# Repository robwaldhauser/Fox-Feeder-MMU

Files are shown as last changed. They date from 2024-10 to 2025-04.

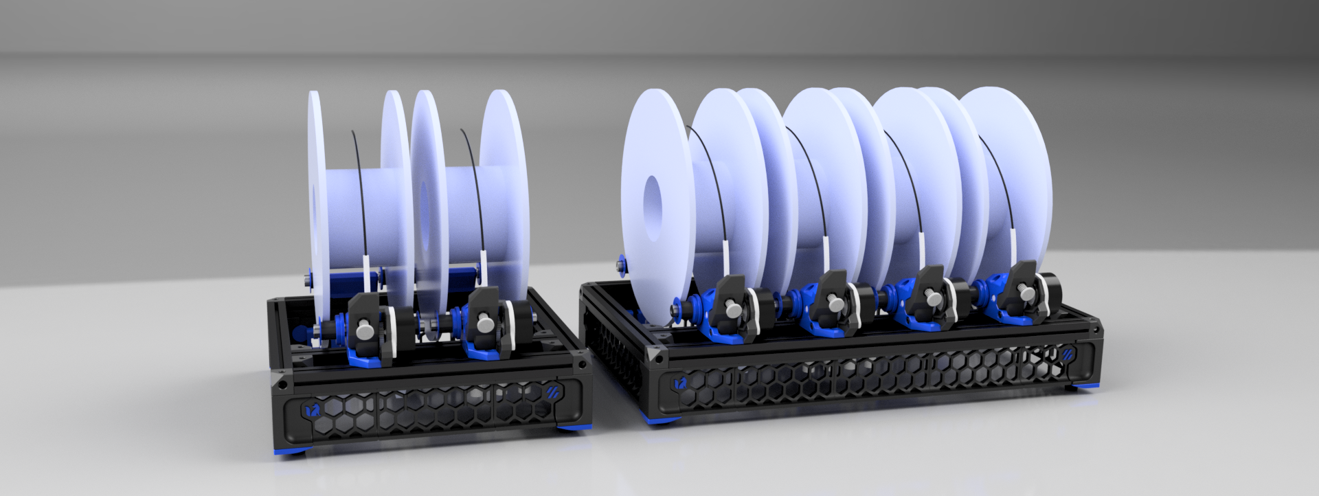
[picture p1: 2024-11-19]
Fox Feeder v138.png

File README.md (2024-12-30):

# Fox Feeder MMU 🦊

The FoxFeeder MMU is a low-cost, easy-to-build multi-material unit (MMU) designed to bring advanced multi-material printing capabilities to any 3D printer running Klipper. Inspired by the functionality of the BambuLab AMS, the FoxFeeder MMU is a lightweight low-cost solution that pairs seamlessly with the FriendlyFox macro package and the innovative Slacker sensor for precise filament tracking.
Fox Feeder v138
If you like this project, consider [tipping](https://www.Ko-fi.com/robxberty)!

## Features ✨

- Affordable: Designed with cost-effective components, making multi-material printing accessible.
- Customizable Lanes: Choose between 2-lane or 4-lane configurations to suit your needs (additional lanes may be supported in the future)
- Slacker Sensor Integration: Utilizes the Slacker Sensor for real-time monitoring of filament slack and tension through the Bowden tube, ensuring consistent filament flow.
- Seamless Integration: Built to work flawlessly with the FriendlyFox macro package. One .cfg to add and that's it, no plugins needed!
- Ease of Assembly: A straightforward assembly process suitable for hobbyists and newcomers alike.

## Table of Contents 📖

- Introduction
- [Features](https://github.com/robwaldhauser/Fox-Feeder-MMU#features-)
- [Requirements](https://github.com/robwaldhauser/Fox-Feeder-MMU#requirements-)
- [Assembly Instructions](https://github.com/robwaldhauser/Fox-Feeder-MMU#assembly-instructions-)
- [Configuration](https://github.com/robwaldhauser/Fox-Feeder-MMU#configuration-)
- [Usage](https://github.com/robwaldhauser/Fox-Feeder-MMU#usage-)
- [Roadmap](https://github.com/robwaldhauser/Fox-Feeder-MMU#roadmap-)
- [Contributing](https://github.com/robwaldhauser/Fox-Feeder-MMU#contributing-)
- [License](https://github.com/robwaldhauser/Fox-Feeder-MMU#license-)

## Requirements 🛠️

- A 3D printer with Bowden setup or compatible extruder system.
- A set of printed components for the FoxFeeder (STL files available in the STLs directory).
- Hardware kit (refer to the Bill of Materials).
- Slacker Sensor for filament slack detection (available from the Slacker repository).
- FriendlyFox Macro Package (available from the FriendlyFox repository).

## Printing Instructions

- Designed to follow Voron printing standards. General rule is 0.4mm line widths, 4 walls, 5 tops and bottoms, and 40% infill. Adjust at your own risk.
- All items with an [a] prefix are intended to be your accent color
- All items with a [s] prefix are best to be printed in a [s]oft but not too [s]quishy filament to keep things [s]ilent. This can be a medium to hard tpu.
- All items that need supports, have them built in.
- The Roller Clutch Inner parts are designed to have an overhang for the pinwheels. You will want to gently free them up after printing but before assembly.

## Assembly Instructions 🔧

- Assemble your frame using Corner Cubes. The center cross bar will need to have a 31mm gap between it and the front extrusion. The tapered corners of the Corner Cubes will face up and outward.
- Feet and Skirts assemble exactly like a Voron 0.
- **more instructions to come, this is currently being updated**

## Configuration ⚙️

To integrate the FoxFeeder MMU with your printer and firmware:

- Install the FriendlyFox Macro Package, simply copy the FriendlyFox.cfg file into your Klipper instance. Be sure to include it in your printer.cfg
- Configure your slicer to define the number of active lanes.
- Update your printer's Klipper configuration with the provided example configurations in configs/.

## Usage 🚀

Once set up, the FoxFeeder MMU will:

- Detect and manage filament slack using the Slacker Sensor.
- Switch lanes seamlessly during multi-material prints.
- Operate efficiently and reliably under the control of the FriendlyFox macros.

Refer to the Usage Guide for detailed instructions.

## Roadmap 🛣️

- Add support for more lanes (e.g., 6-lane or 8-lane configurations).
- Improve documentation and troubleshooting guides.
- Create community challenges and showcases.

## Contributing 🤝

Contributions are welcome! Feel free to submit issues, feature requests, and pull requests. Check the Contributing Guide for more details.
Please also consider [tipping](https://www.Ko-fi.com/robxberty) to help with further development!

## License 📄

This project is licensed under the MIT License.

## Join the FoxFeeder revolution and unleash the power of multi-material printing without breaking the bank! 🦊

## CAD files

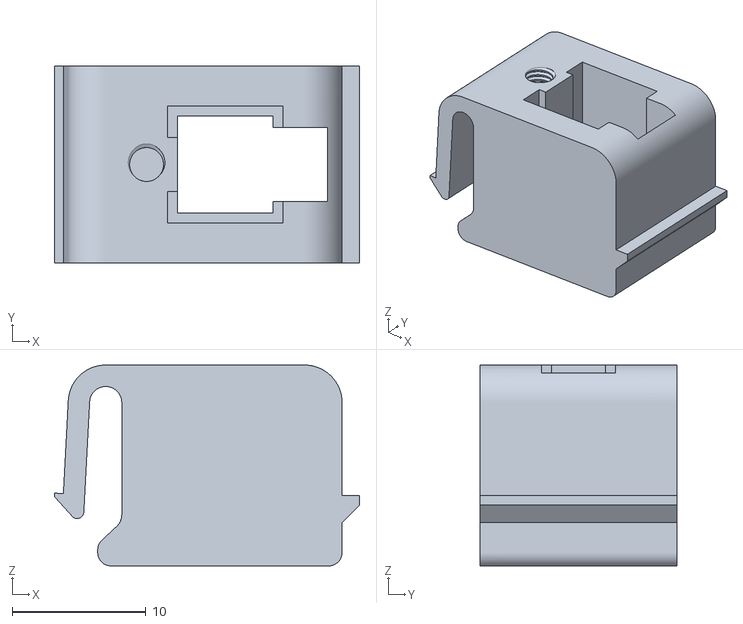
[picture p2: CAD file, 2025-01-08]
STLs/Electronics/Micro-Fit 2x2 Keystone.stl
22.8 x 14.7 x 15.0

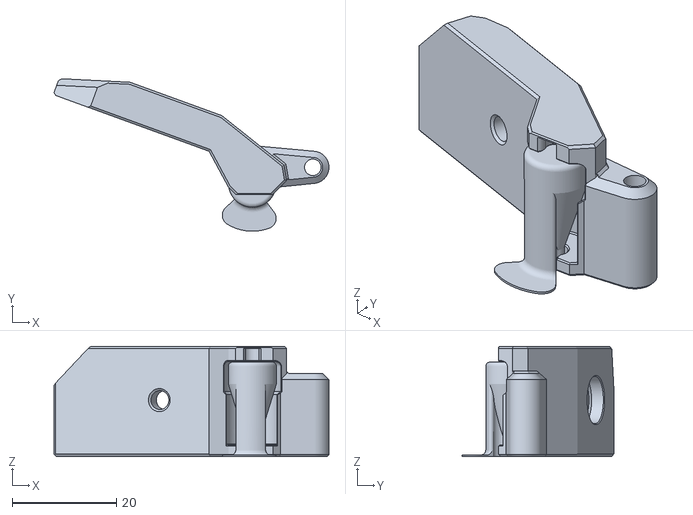
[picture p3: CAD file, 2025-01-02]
STLs/Extruder/Tensioner Arm xN.stl
52.7 x 29.2 x 21.1

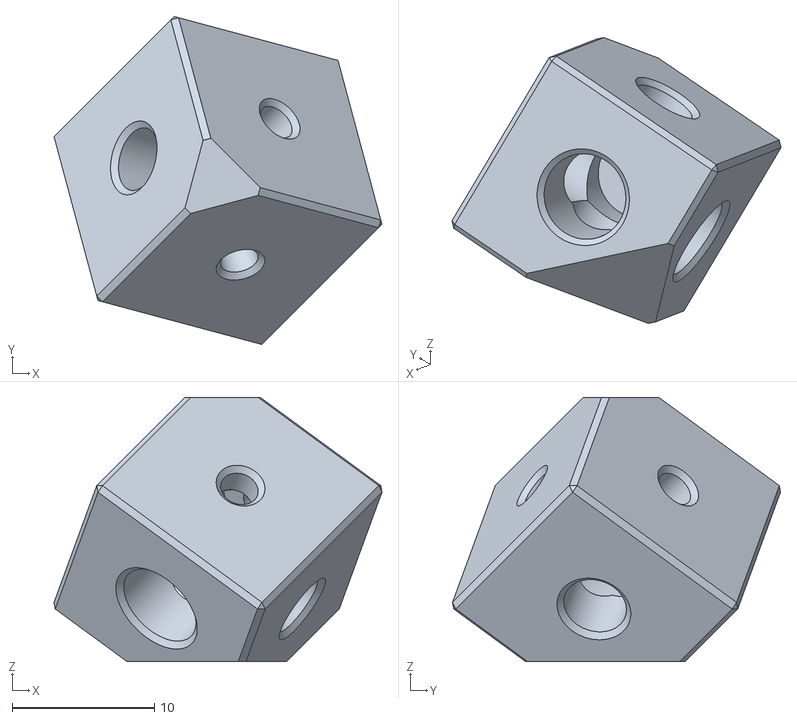
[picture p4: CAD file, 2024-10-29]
STLs/Frame/Corner Cube x8.stl
23.0 x 23.0 x 18.6

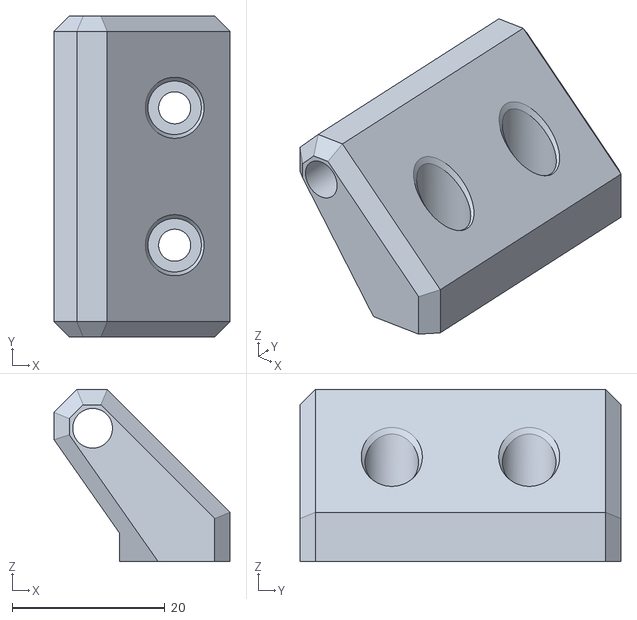
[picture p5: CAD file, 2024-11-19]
STLs/Idler/[a] Idler Body xN.stl
23.1 x 42.0 x 22.5

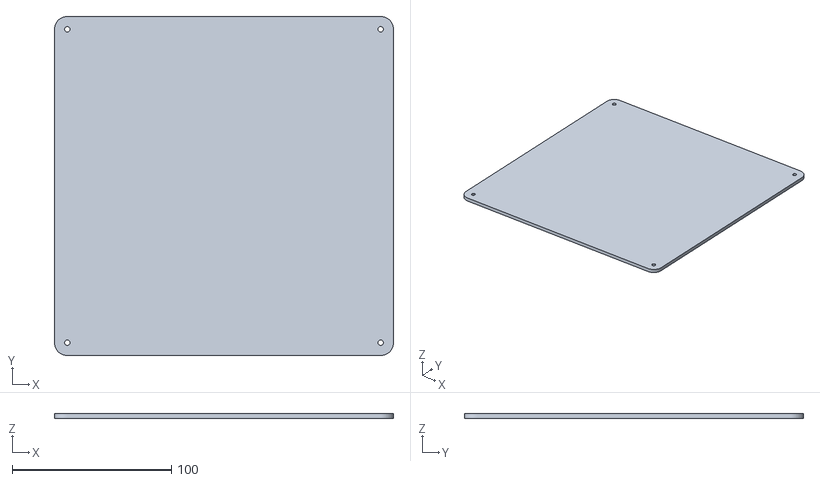
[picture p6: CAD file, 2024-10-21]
STLs/Panels/Bottom Panel.stl
213.0 x 213.0 x 3.00

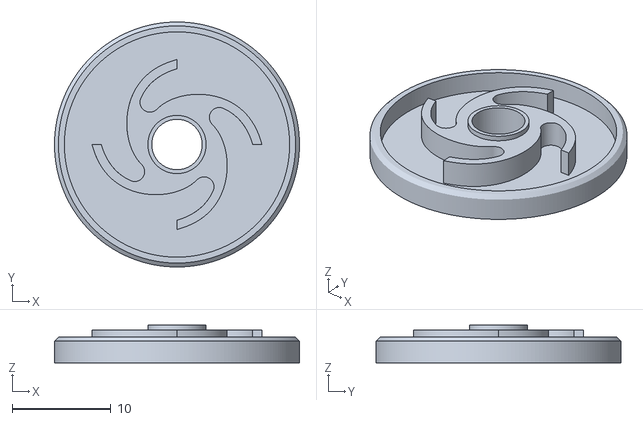
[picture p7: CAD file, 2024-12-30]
STLs/Rollers (TPU)/[s] Left Roller Clutch Inner xN.stl
24.8 x 24.8 x 3.80

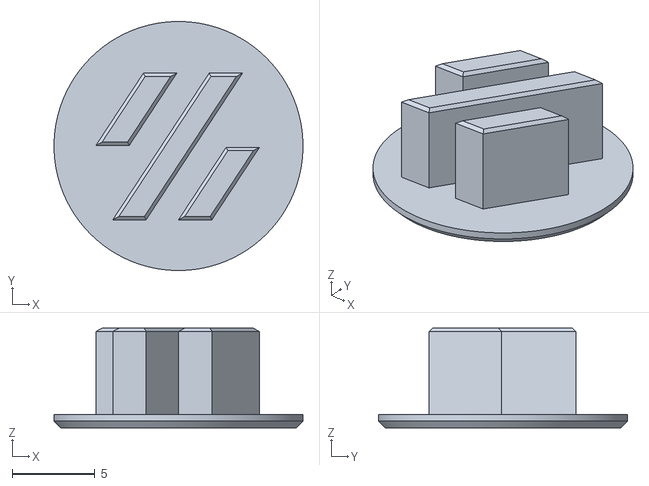
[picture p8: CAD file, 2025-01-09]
STLs/Skirts/(a) V Logo Insert.stl
15.0 x 15.0 x 6.00

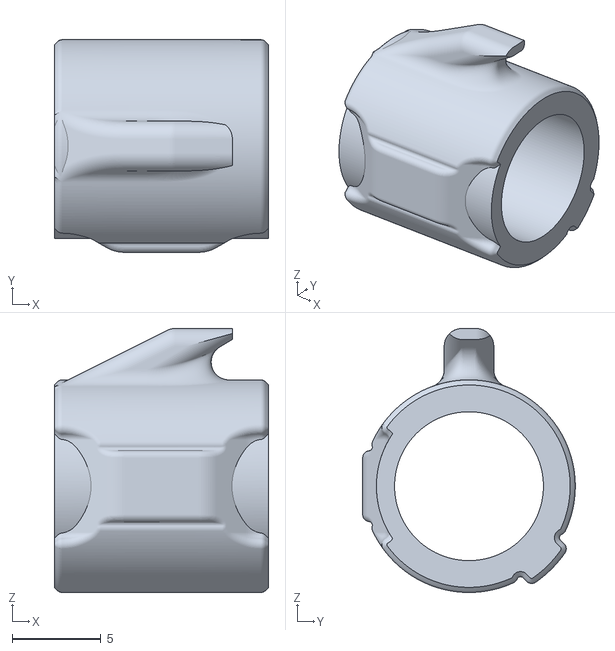
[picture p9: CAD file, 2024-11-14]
STLs/Slacker/[a] Slider W Bands.stl
12.1 x 12.0 x 14.9

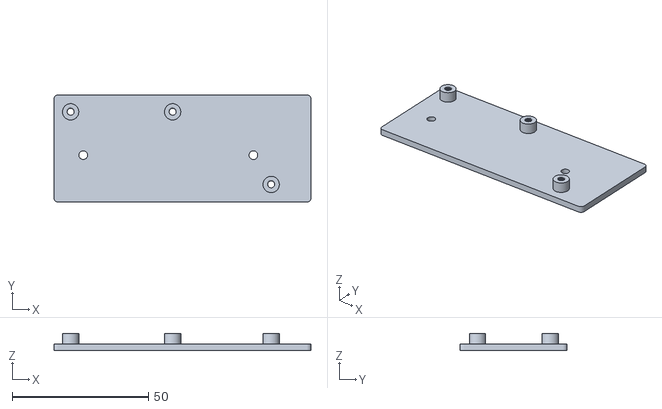
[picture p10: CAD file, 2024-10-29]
STLs/Electronics/ERB Bracket.stl
94.4 x 39.4 x 6.40

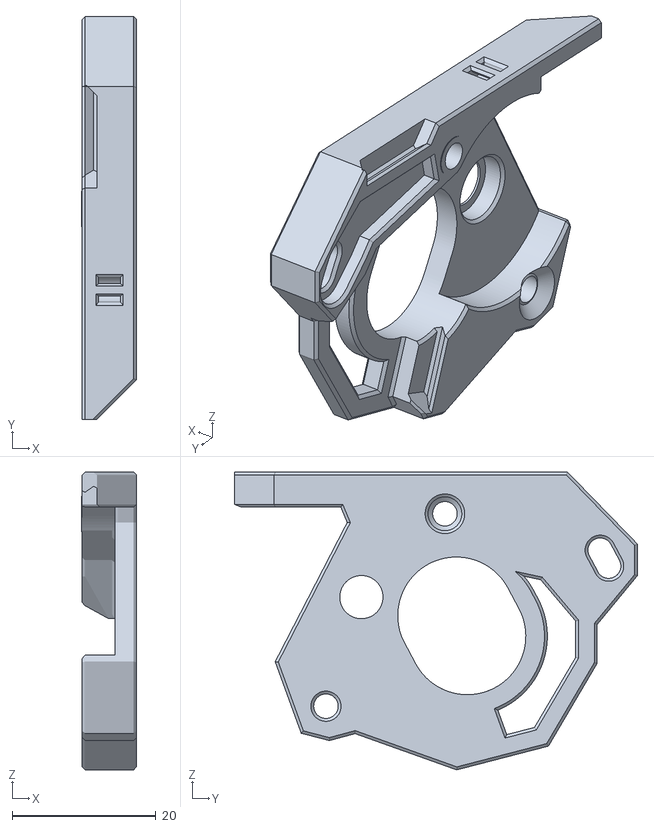
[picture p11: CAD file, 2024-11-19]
STLs/Extruder/Motor Plate xN.stl
7.65 x 56.0 x 41.4

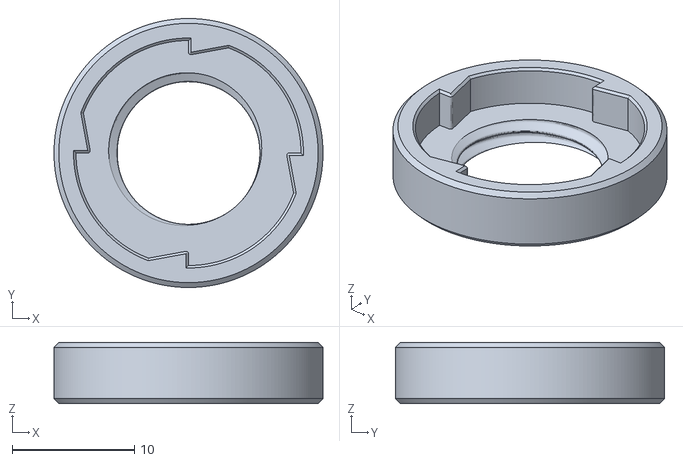
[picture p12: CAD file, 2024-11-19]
STLs/Rollers (TPU)/[s] Right Roller Clutch Outer xN.stl
22.0 x 22.0 x 5.00

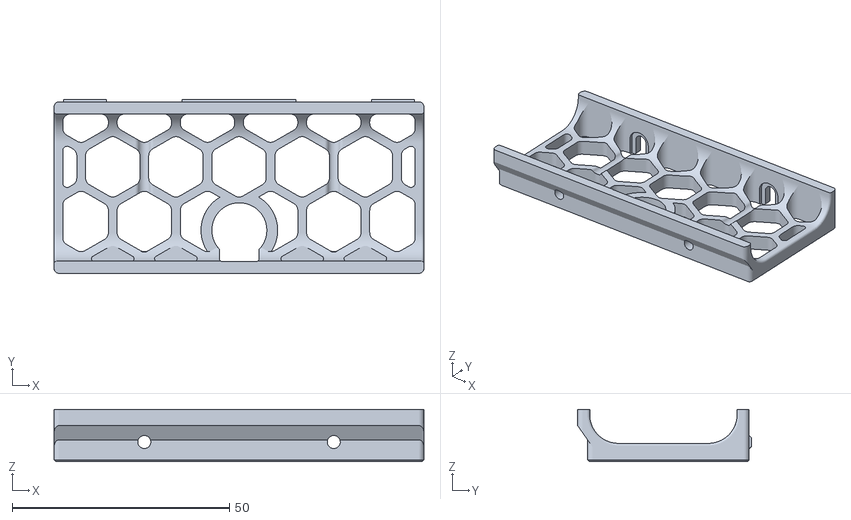
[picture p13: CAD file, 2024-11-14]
STLs/Skirts/Rear Center Skirt Slacker.stl
85.2 x 40.0 x 12.0

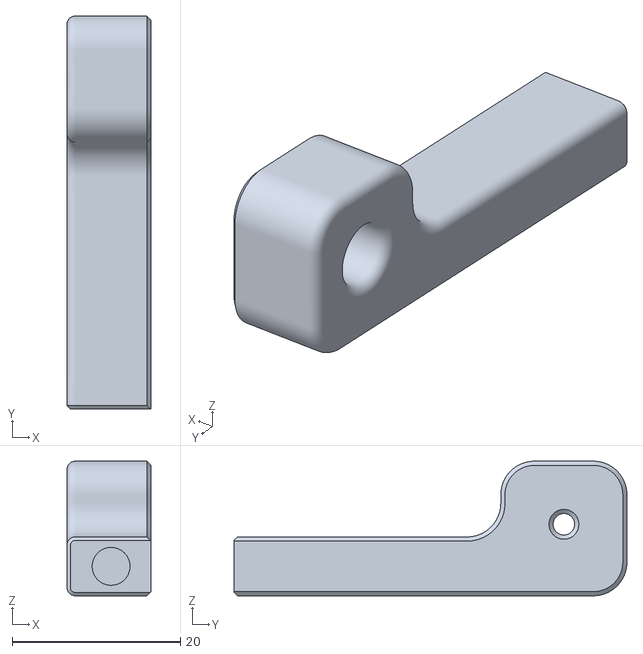
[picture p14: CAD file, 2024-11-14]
STLs/Slacker/Slacker Brace.stl
10.0 x 46.7 x 16.0

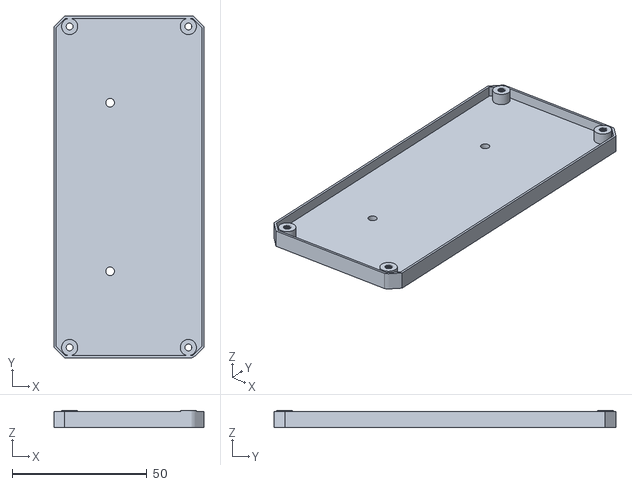
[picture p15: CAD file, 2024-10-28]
STLs/Electronics/MMB Bracket.stl
55.6 x 126.6 x 6.40

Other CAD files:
STLs/Extruder/[a] Extruder Body xN.stl
STLs/Skirts/Foot B x2.stl
STLs/Slacker/Sensor Housing w Bands.stl
STLs/Rollers (TPU)/[s] Right Roller Clutch Inner xN.stl
STLs/Rollers (TPU)/OLD [s] Left Roller Clutch Inner xN.stl
STLs/Rollers (TPU)/[s] Idler Inner x2N.stl
STLs/Rollers (TPU)/[s] Left Roller Clutch Outer xN.stl
STLs/Rollers (TPU)/[s] Roller x4N.stl
STLs/Skirts/(a) Foot Accent A x2.stl
STLs/Skirts/(a) Foot Accent B x2.stl
STLs/Skirts/(a) Fox Logo Insert x2.stl
STLs/Skirts/(s) Rubber Foot x4.stl
STLs/Skirts/Foot A x2.stl
STLs/Skirts/Front Center Skirt.stl
STLs/Skirts/Rear Left Skirt.stl
STLs/Skirts/Side Skirt A x2.stl
STLs/Skirts/Side Skirt B x2.stl
STLs/Skirts/Skirt A x2.stl
STLs/Skirts/Skirt B.stl
STLs/Slacker/Slider.stl

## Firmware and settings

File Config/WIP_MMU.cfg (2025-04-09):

[force_move]
enable_force_move: True
#   Set to true to enable FORCE_MOVE and SET_KINEMATIC_POSITION
#   extended G-Code commands. The default is false.

#Variable Store
[gcode_macro _FILAMENT_VARS]
variable_activelane: None
variable_lane_count: 2 # Number of lanes to look for
variable_infinitespool: 1
variable_bowden_length: 980 # Run the MEASURE_BOWDEN macro to get an estimate for this value
variable_filament_feed_length: 105 # The amount of travel needed to clear extruder on filament removal.
variable_stepper_accel: 150
variable_stepper_speed: 45
variable_bowden_calculate: 0
variable_pause_flag: False
variable_slacker_enabled: False
gcode: # Gcode section left intentionally blank. Do not disturb.

    {action_respond_info(" Running the VARIABLE_STORE macro does nothing")}

[mcu pcu]
canbus_uuid: 2c180b4d19b3

# Aliases for easier configuration.

[board_pins pcu_alias]
mcu: pcu
aliases:
aliases_both_sides:
  taut=PA3,
  slack=PA4,
aliases_lane0:
  sensor_0=PB9,
  lane0_step=PB15,
  lane0_dir=PB14,
  lane0_enable=PA8,
  lane0_uart=PA10,
aliases_lane1:
  sensor_1=PB8,
  lane1_step=PD2,
  lane1_dir=PB13,
  lane1_enable=PD1,
  lane1_uart=PC7,


#
# Below are the stepper configs, you will need one for each lane
#

[extruder_stepper stepper_0]
extruder: 
step_pin: pcu:lane0_step
dir_pin: pcu:lane0_dir
enable_pin: !pcu:lane0_enable
microsteps: 16
rotation_distance: 22 
gear_ratio: 50:10 # CW2 gear ratio
microsteps: 16
full_steps_per_rotation: 200

[tmc2209 extruder_stepper stepper_0]
uart_pin: pcu:lane0_uart
run_current: 0.8
hold_current: .1
stealthchop_threshold: 0
interpolate: True

[extruder_stepper stepper_1]
extruder: 
step_pin: pcu:lane1_step
dir_pin: pcu:lane1_dir
enable_pin: !pcu:lane1_enable
microsteps: 16
rotation_distance: 22 #16.27062274656 
gear_ratio: 50:10 # CW2 gear ratio
microsteps: 16
full_steps_per_rotation: 200

[tmc2209 extruder_stepper stepper_1]
uart_pin: pcu:lane1_uart
run_current: 0.8
hold_current: .1
stealthchop_threshold: 0
interpolate: True

#
# Sensors below, you will need 1 Belay sensor and then 1 sensor for each lane
#

#[belay belay0]
#extruder_type: extruder_stepper
#extruder_stepper_name: stepper_1
#sensor_pin: ^!pcu:belay
#multiplier_high: 1.3
#multiplier_low: .7
#debug_level: 1

[filament_switch_sensor taut]
switch_pin: ^!pcu:taut
pause_on_runout: False
runout_gcode:
  {% set lane = printer["gcode_macro _FILAMENT_VARS"].activelane %}
  RESPOND MSG="Lane {lane}: TAUT"
  FORCE_MOVE STEPPER="extruder_stepper stepper_{lane}" DISTANCE=6 VELOCITY=50 ACCEL=600

[filament_switch_sensor slack]
switch_pin: ^!pcu:slack
pause_on_runout: False
runout_gcode:
  {% set lane = printer["gcode_macro _FILAMENT_VARS"].activelane %}
  RESPOND MSG="Lane {lane}: SLACK"
  FORCE_MOVE STEPPER="extruder_stepper stepper_{lane}" DISTANCE=-6 VELOCITY=50 ACCEL=600

[filament_switch_sensor sensor_0]
switch_pin: ^pcu:sensor_0
pause_on_runout: False

[filament_switch_sensor sensor_1]
switch_pin: ^pcu:sensor_1
pause_on_runout: False

#
# Macros:
#

[gcode_macro SYNC_EXTRUDER]
gcode:
  {% set lane = params.LANE %}
  {% if not printer['extruder_stepper stepper_' + lane|string].motion_queue == 'extruder' %}
    SYNC_EXTRUDER_MOTION EXTRUDER=stepper_{lane} MOTION_QUEUE=extruder
  {% endif %}

[gcode_macro ISOLATE_EXTRUDER]
gcode:
  {% set lane = params.LANE %}
  {% if printer['extruder_stepper stepper_' + lane|string].motion_queue == 'extruder' %}
    SYNC_EXTRUDER_MOTION EXTRUDER=stepper_{lane} MOTION_QUEUE=
  {% endif %}

[gcode_macro CHECK_STATUS]
gcode:
  {% set lane = 0 %}
  {% set stepper_accel = printer["gcode_macro _FILAMENT_VARS"].stepper_accel %}
  {% for lane in range(printer["gcode_macro _FILAMENT_VARS"].lane_count) %}
    {% if printer['filament_switch_sensor sensor_' + lane|string].filament_detected and not printer["filament_switch_sensor taut"].filament_detected %}
      ISOLATE_EXTRUDER LANE={lane}
      FORCE_MOVE STEPPER="extruder_stepper stepper_{lane}" DISTANCE=6 VELOCITY=50 ACCEL={stepper_accel}
      M400 # Wait for buffer to clear
      {% set step = 0 %}
      {% for step in range(10) %}
        M400
        _PUSHING_CHECK LANE={lane} STEP={step}
        M400
      {% endfor %}
    {% elif printer['filament_switch_sensor sensor_' + lane|string].filament_detected %}
      ISOLATE_EXTRUDER LANE={lane}
      FORCE_MOVE STEPPER="extruder_stepper stepper_{lane}" DISTANCE=-6 VELOCITY=50 ACCEL={stepper_accel}
      M400 # Wait for buffer to clear
      {% set step = 0 %}
      {% for step in range(350) %}
        M400
        _PULLING_CHECK LANE={lane} STEP={step}
        M400
      {% endfor %}
    {% elif not printer['filament_switch_sensor sensor_' + lane|string].filament_detected %}
      ISOLATE_EXTRUDER LANE={lane}
      FORCE_MOVE STEPPER="extruder_stepper stepper_{lane}" DISTANCE=20 VELOCITY=50 ACCEL={stepper_accel}
      M400 # Wait for buffer to clear
      _CHECKING_LANE LANE={lane}
    #{% elif printer['filament_switch_sensor sensor_' + lane|string].filament_detected and not printer["filament_switch_sensor slack"].filament_detected %}
    #  ISOLATE_EXTRUDER LANE={lane}
    #  FORCE_MOVE STEPPER="extruder_stepper stepper_{lane}" DISTANCE=-10 VELOCITY=50 ACCEL={stepper_accel}
    #  M400 # Wait for buffer to clear
    #  _CHECKING_BELAY LANE={lane}
    {% else %}
      RESPOND MSG="Lane {lane}: No Filament is loaded"
    {% endif %}
  {% endfor %}

[gcode_macro _PUSHING_CHECK]
gcode:
  {% set lane = params.LANE %}
  {% set step = params.STEP|int %}
  {% set stepper_accel = printer["gcode_macro _FILAMENT_VARS"].stepper_accel %}
  {% if printer["filament_switch_sensor slack"].filament_detected and printer['filament_switch_sensor sensor_' + lane|string].filament_detected %}
    ISOLATE_EXTRUDER LANE={lane}
    M400
    FORCE_MOVE STEPPER="extruder_stepper stepper_{lane}" DISTANCE=6 VELOCITY=50 ACCEL={stepper_accel} 
    M400
  {% endif %}
  {% if step == 9 and not printer["filament_switch_sensor slack"].filament_detected and printer['filament_switch_sensor sensor_' + lane|string].filament_detected %}
    RESPOND MSG="Lane {lane} - Filament is at toolhead"
    SET_LANE LANE={lane}
  {% elif step == 9 %}
    REMOVE_FILAMENT LANE={lane}  SKIPCHECK=True
    RESPOND MSG="Lane {lane} - Filament is ready"
  {% endif %}

[gcode_macro _PULLING_CHECK]
gcode:
  {% set lane = params.LANE %}
  {% set step = params.STEP|int %}
  {% set stepper_accel = printer["gcode_macro _FILAMENT_VARS"].stepper_accel %}
  {% if printer["filament_switch_sensor taut"].filament_detected and printer['filament_switch_sensor sensor_' + lane|string].filament_detected %}
    ISOLATE_EXTRUDER LANE={lane}
    M400
    FORCE_MOVE STEPPER="extruder_stepper stepper_{lane}" DISTANCE=-6 VELOCITY=50 ACCEL={stepper_accel} 
    M400
  {% endif %}
  {% if step == 349 and not printer["filament_switch_sensor taut"].filament_detected and printer['filament_switch_sensor sensor_' + lane|string].filament_detected %}
    RESPOND MSG="Lane {lane} - Filament is at toolhead"
    SET_LANE LANE={lane}
  {% elif step == 349 %}
    RESPOND MSG="Lane {lane} - Filament is ready"
  {% endif %}

[gcode_macro _CHECKING_LANE]
gcode:
  {% set lane = params.LANE %}
  {% if not printer['filament_switch_sensor sensor_' + lane|string].filament_detected %}
    RESPOND MSG="Lane {lane}: No Filament is loaded"
  {% else %}
    REMOVE_FILAMENT LANE={lane}  SKIPCHECK=True
    RESPOND MSG="Lane {lane}: Filament is ready"
  {% endif %}

[gcode_macro SET_LANE]
gcode:
  {% set specified = params.SPECIFIED|default(None) %}
  {% if not specified == None %}
    RESPOND MSG="Activating Lane {specified}"
    SET_GCODE_VARIABLE MACRO=_FILAMENT_VARS VARIABLE=activelane VALUE={specified}
  {% elif printer['filament_switch_sensor sensor_0'].filament_detected and printer['filament_switch_sensor sensor_1'].filament_detected %}
    RESPOND TYPE=error msg="!! UNABLE TO DETECT SPOOL, BOTH SENSORS TRIGGERED !!"
  {% elif printer['filament_switch_sensor sensor_0'].filament_detected and not printer['filament_switch_sensor sensor_1'].filament_detected %}
    RESPOND MSG="Activating Lane 0"
    SET_GCODE_VARIABLE MACRO=_FILAMENT_VARS VARIABLE=activelane VALUE=0
  {% elif printer['filament_switch_sensor sensor_1'].filament_detected and not printer['filament_switch_sensor sensor_0'].filament_detected %}
    RESPOND MSG="Activating Lane 1"
    SET_GCODE_VARIABLE MACRO=_FILAMENT_VARS VARIABLE=activelane VALUE=1
  {% else %}
    RESPOND TYPE=error msg="!! UNKNOWN SPOOL CONFIGURATION !!"
  {% endif %}

[delayed_gcode INITIAL_SET_LANE]
initial_duration: 5
gcode:
  SET_FILAMENT_SENSOR SENSOR=taut ENABLE=0
  SET_FILAMENT_SENSOR SENSOR=slack ENABLE=0
  CHECK_STATUS
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

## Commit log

2024-10-21 Updates to STLs
    [(a) Extruder Body x(N).stl, (a) Foot Accent x4.stl, (a) Idler Bracket x(N).stl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]
2024-10-21 Update STLs
    [(a) Foot Accent A x2.stl, (a) Foot Accent B x2.stl, (a) Foot Accent x4.stl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]
2024-10-21 STL's Updates
    [(a) Logo Insert x4.stl, Bottom Panel.stl, Y Splitter Body.stl]
2024-10-28 Updates to STLs Folder
    [(a) Belay Slider.stl, (a) Extruder Body x(N).stl, (a) Fox Logo Insert x2.stl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]
2024-10-29 oriented stls
    fixed stl orientations
    [(a) Belay Slider.stl, (a) Extruder Body x(N).stl, (a) Fox Logo Insert x2.stl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]
2024-10-29 Updated CAD
2024-10-29 Update Belay Brace.stl
    accidentally saved cover as brace. fixed
    [Belay Brace.stl]
2024-10-29 Update Extruder Tension Arm x(N).stl
    [Extruder Tension Arm x(N).stl]
2024-10-29 orientation adjsted for printing
    fixed orientation
    [Corner Cube x8.stl, Extruder Tension Arm x(N).stl]
2024-10-29 Updated STLs
    [(a) Extruder Body x(N).stl, (a) Roller Caps x(4N).stl, Cap.stl]
2024-11-03 Updated CAD and STLS
    [(a) Extruder Body x(N).stl, (a) Idler Bracket x(N).stl, (s) Extruder Roller Sleeve Left x(N).stl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]
2024-11-05 STL Updates
    [Extruder Motor Plate xN.stl, Extruder Roller Gear x(2N).stl, Extruder Tension Arm xN.stl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]
2024-11-05 Updated Rollers
    [Front Roller Inner xN.stl, Front Roller Outer x2N.stl, Roller Front Inner Left xN.stl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]
2024-11-05 Update Roller STLs
    [Idler Inner x2N.stl, Idler Outer x2N.stl]
2024-11-05 CAD Update
2024-11-05 Create mmu roller gears beefed.step
    beefed up roller gear fingers
    [mmu roller gears beefed.step]
2024-11-14 add slacker
    [Center Rear Skirt.stl, Cover.stl, Front Center Skirt.stl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]
2024-11-15 Create BOM
2024-11-16 Update BOM
2025-01-02 Update Tensioner Arm xN.stl
    [Tensioner Arm xN.stl]
2025-01-08 Create Micro-Fit 2x2 Keystone.stl
    [Micro-Fit 2x2 Keystone.stl]
2025-01-09 Update (a) V Logo Insert.stl
    [(a) V Logo Insert.stl]
